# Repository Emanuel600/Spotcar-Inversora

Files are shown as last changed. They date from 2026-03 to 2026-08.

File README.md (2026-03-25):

# Spotcar Inversora
Projeto TCC, constituindo uma repuxadeira elétrica. Planilha de cálculo no arquivo Planilha_de_Cálculo.pynb; separado nas seguintes partes:
 - "Kicad - Projects" - placas que serão construídas, inclui versões alternativas que não serão utilizadas
 - "Spotcar Codebase" - código do microcontrolador escolhido

## Visão Geral
 - Visa principalmente reduzir volume, peso e custo do produto atualmente no mercado (50x40x40cm e 19,5 kg)
 - Deve ser capaz de realizar solda por resistência através da ponteira de solda (mínimo 10A, máximo ~200A)
 - Utilizada para desamassar peças metálicas de carros - não recomendada para lataria de alumínio

## Especificações Técnicas do Sistema
 - Tensão de entrada 220 V @ 60 Hz
 - Potência nominal de saída 2 kVA
 - Corrente máxima de saída 200 A
 - Frequência da corrente de saída 40 kHz
 - Tensão RMS de saída em vazio 10 V (onda quadrada)
 - Tecnologia inversora (Dada a potência, provável o uso de IGBTs)
 - Proteção de sobrecorrente, sobretemperatura e possívelmente subtensão na entrada

## Topologia
Devido à potência relativamente baixa e para reduzir a complexidade do comando - foi escolhida a topologia meia ponte.

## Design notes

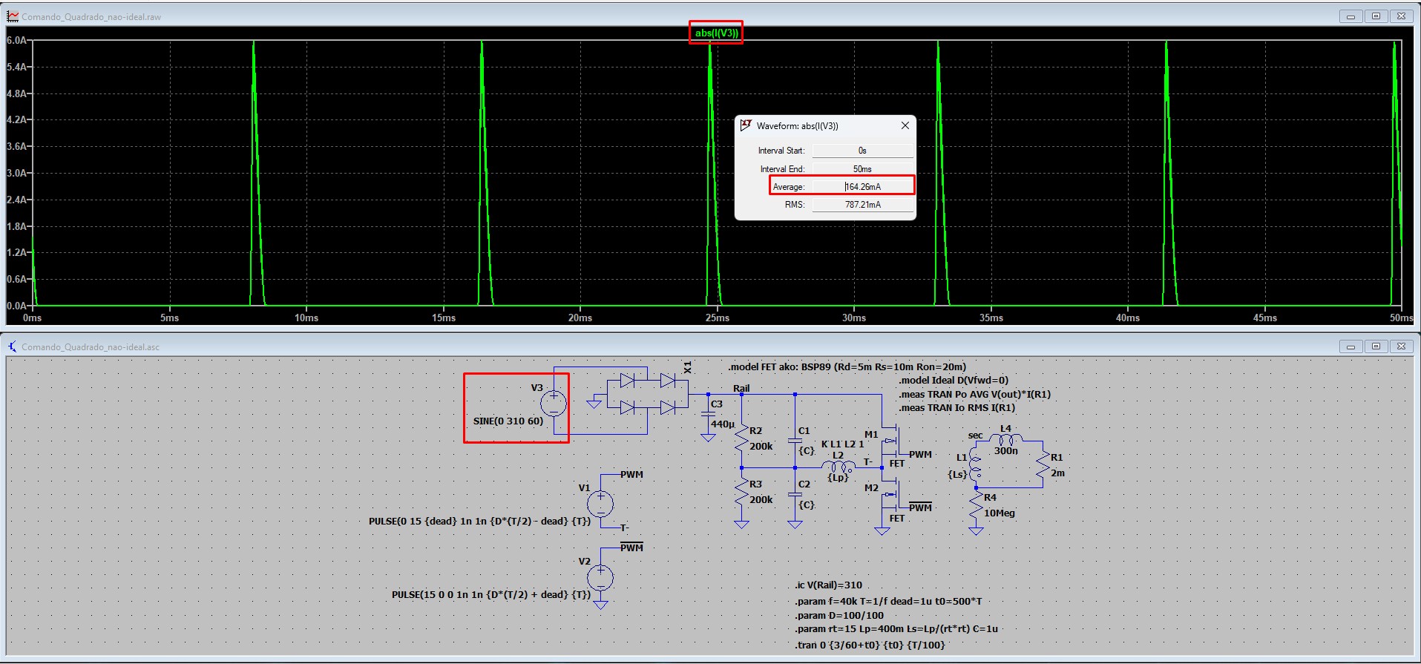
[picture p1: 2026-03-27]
screenshot.jpg

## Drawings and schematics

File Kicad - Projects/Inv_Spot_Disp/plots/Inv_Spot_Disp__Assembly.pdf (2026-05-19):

33u C1

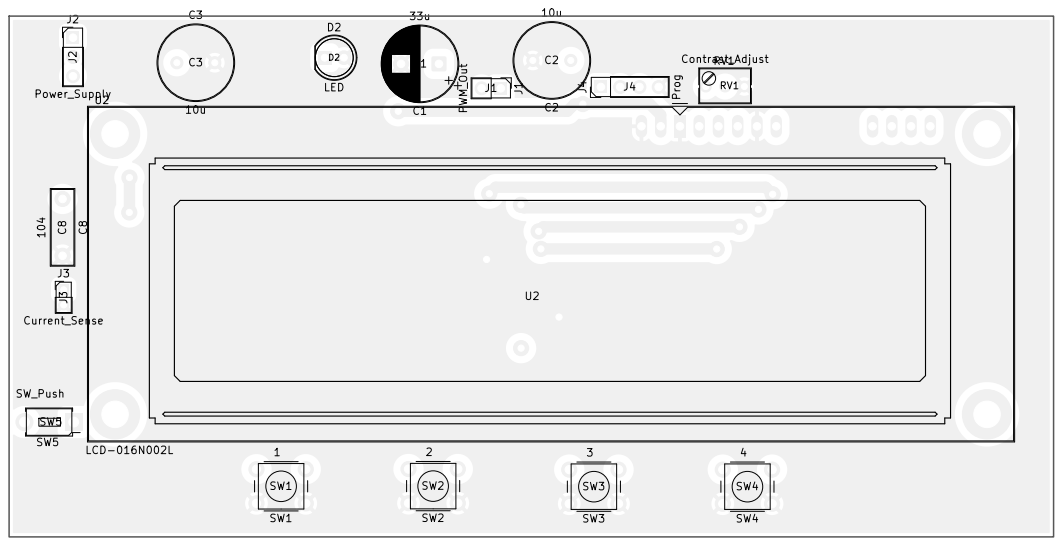
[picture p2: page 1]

Board2Pdf: Black And White TOP - Page 1/2

Sheet: Black And White TOP
File: Inv_Spot_Disp.kicad_pcb
Title:
KiCad E.D.A. 10.0.1

Board2Pdf: Black And White BOT - Page 2/2 ¹k5 | R14 4k | R4 | 104 C6 | 3k3

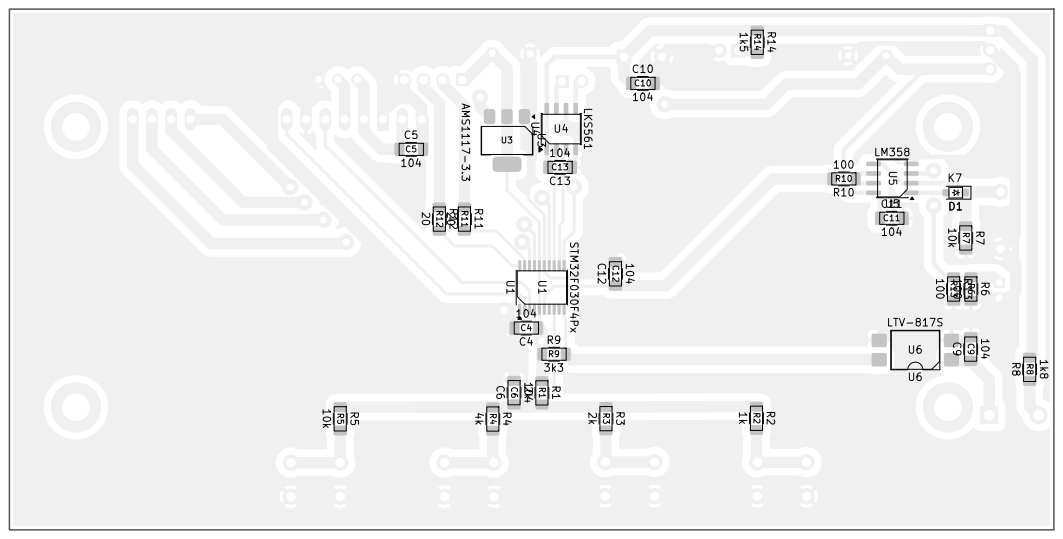
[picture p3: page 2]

Sheet: Black And White BOT
File: Inv_Spot_Disp.kicad_pcb
Title:
KiCad E.D.A. 10.0.1

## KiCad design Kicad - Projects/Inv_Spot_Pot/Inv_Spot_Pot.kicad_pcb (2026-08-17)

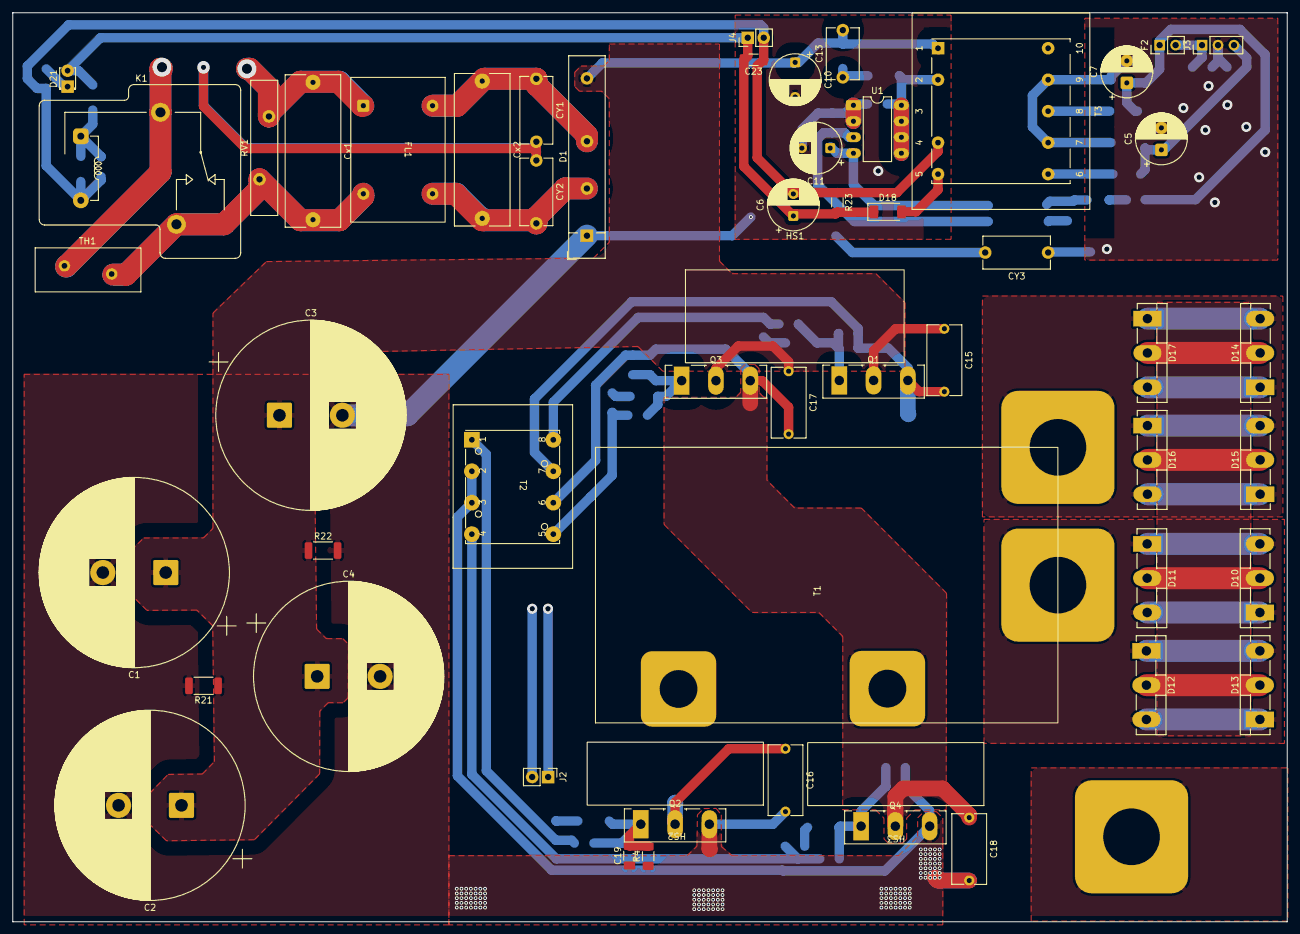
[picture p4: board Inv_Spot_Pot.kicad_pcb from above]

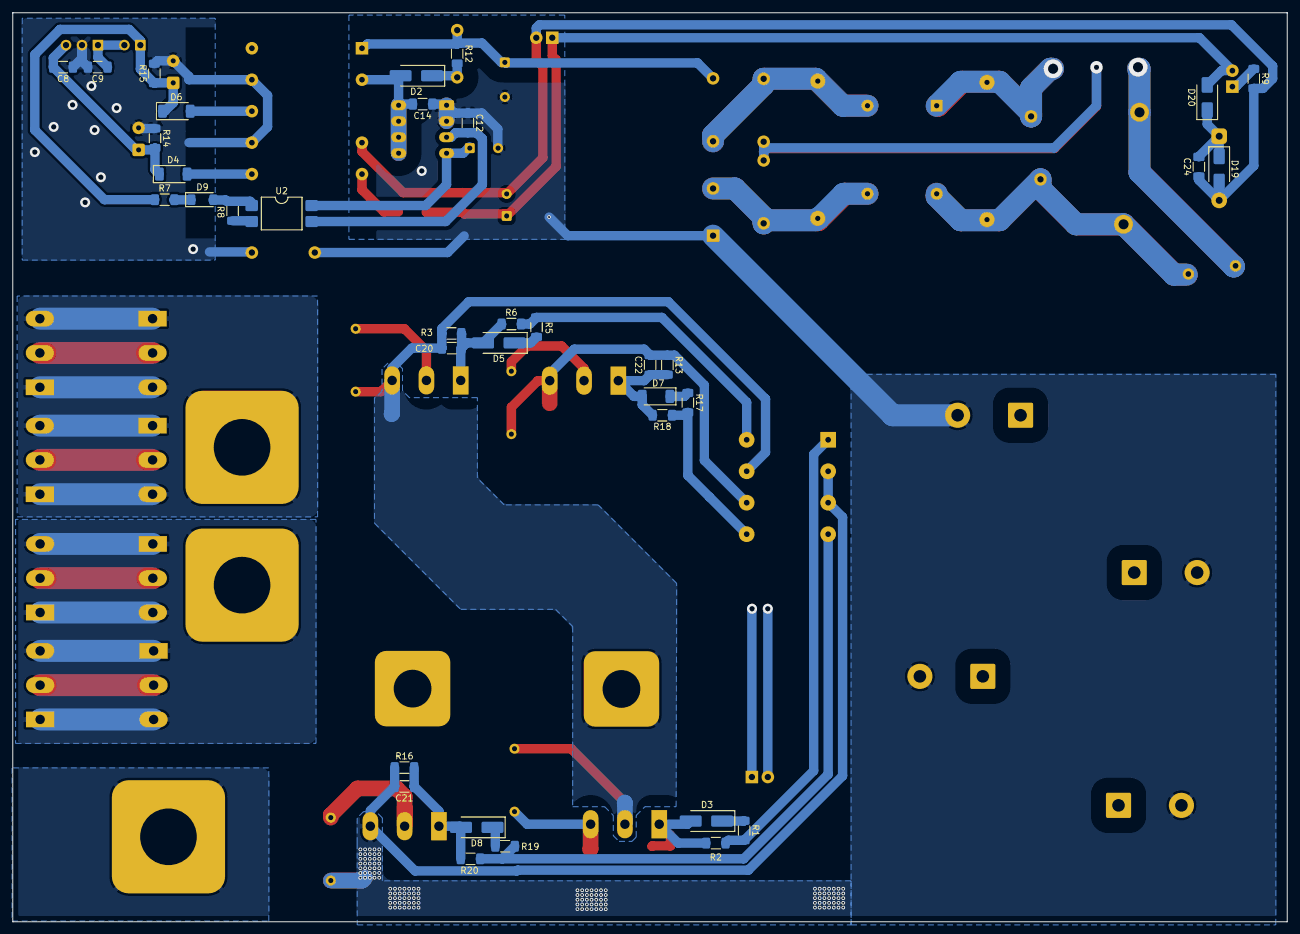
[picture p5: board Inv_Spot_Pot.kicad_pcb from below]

Board: 2 copper layers, 202.6 x 144.5 mm, 91 parts (36 on the bottom side), 42 nets.

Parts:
C1, C2, C3, C4: 220u; CP_Radial_D30.0mm_P10.00mm_SnapIn
C5, C6, C7: 220u; CP_Radial_D8.0mm_P3.50mm
C8, C9, C14, C19, C20, C21, C22, C23, C24: 100n; C_1206_3216Metric_Pad1.33x1.80mm_HandSolder
C10, C11: 47u; CP_Radial_D8.0mm_P3.50mm
C12: 1n; C_1206_3216Metric_Pad1.33x1.80mm_HandSolder
C13: 47p; C_Disc_D8.0mm_W5.0mm_P7.50mm
C15, C16, C17, C18: 100n; C_Rect_L11.0mm_W5.3mm_P10.00mm_MKT
CY1, CY2, CY3: C; C_Disc_D10.5mm_W5.0mm_P10.00mm
Cx1, Cx2: C; C_Rect_L24.0mm_W8.6mm_P22.50mm_MKT
D1: KBU4M; Diode_Bridge_32.0x5.6x17.0mm_P10.0mm_P7.5mm
D2: K7; D_SMA_Handsoldering
D3, D5, D8: SS16; D_SMA_Handsoldering
D4, D6, D7, D18: SS16; D_SOD-128
D9: BZV55B15; D_MiniMELF
D10, D11, D12, D13, D14, D15, D16, D17: MUR80G20; TO-3P-3_Vertical
D19, D20: 1N4007; D_SMA
D21: LED; LED_D1.8mm_W3.3mm_H2.4mm
F2: Polyfuse; PinHeader_1x02_P2.54mm_Vertical
FL1: EMI_Choke; Filtro_Choke
HS1: Heatsink; Heatsink_35x15mm
HS2, HS3: Heatsink; Floating_28x15x70mm
J2: PWM; PinHeader_1x02_P2.54mm_Vertical
J3: Display_Power; PinHeader_1x03_P2.54mm_Vertical
J4: 24V; PinHeader_1x02_P2.54mm_Vertical
K1: Y14x-1C-xxDS; Relay_SPDT_RAYEX-L90
Q1, Q2, Q3, Q4: 40T120; TO-247-3_Vertical
R1, R5, R17, R19: 2; R_1206_3216Metric_Pad1.30x1.75mm_HandSolder
R2, R6, R18, R20: 27; R_1206_3216Metric_Pad1.30x1.75mm_HandSolder
R3, R4, R13, R14, R15, R16, R23: 10k; R_1206_3216Metric_Pad1.30x1.75mm_HandSolder
R7: 510; R_1206_3216Metric_Pad1.30x1.75mm_HandSolder
R8, R12: 2k; R_1206_3216Metric_Pad1.30x1.75mm_HandSolder
R9: 2k2; R_1206_3216Metric_Pad1.30x1.75mm_HandSolder
R21, R22: 200k; R_2010_5025Metric
RV1: Varistor; RV_Disc_D21.5mm_W4.3mm_P10mm
T1: Transformer_1P_2S; Transformer_Toroid_THT_7032
T2: Pulse_Transformer-EEL-25_26x20-4_Windings
T3: Transformer_Breve_TEZ-28x33
TH1: Thermistor_PTC; RV_Disc_D16.5mm_W6.7mm_P7.5mm
U1: DIP-8_W7.62mm_LongPads
U2: LTV-817S; SMDIP-4_W9.53mm

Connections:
7V: C5.1, C8.2, D4.1 (K), J3.3, R14.2
15V: C9.1, F2.2, J3.1
24V: C6.1, C23.2, D18.1 (K), D20.2 (A), D21.2 (A), J4.1, R23.2
310V: C1.1, C2.1, C3.1, C4.1, C10.1, C13.2, C15.1, C17.1, D1.4 (+), Q1.2 (C), Q3.2 (C), R12.1, R21.1, R22.1, T3.1
/Soft_Start-24V/AC_{1}: K1.5, TH1.1
/Soft_Start-24V/AC_{2}: Cx1.1, FL1.1, RV1.1
/Soft_Start-24V/~AC{1}: Cx1.2, FL1.3, K1.1, RV1.2, TH1.2
Earth: C1.2, C2.2, C3.2, C4.2, C10.2, C11.2, C12.1, C14.1, C16.2, C18.2, C19.1, C21.2, CY3.2, D1.1 (-), Q2.3 (E), Q4.3 (E), R4.1, R16.1, R21.2, R22.2, T2.2, T2.3, U1.1 (GND), U1.2 (GND)
Earth_Protective: CY1.2, CY2.1
GND: C5.2, C7.2, C8.1, C9.2, CY3.1, J3.2, R8.2, R14.1, R15.2, T3.7, T3.9, U2.2
GND_{24}: C6.2, C23.1, C24.1, D19.2 (A), J4.2, K1.3, R9.2, R23.1, T3.4
Gate: C20.2, D5.2 (A), Q1.1 (G), R3.2, R6.1
Gate1: C22.1, D7.2 (A), Q3.1 (G), R13.2, R18.1
unnamed: CY1.1, Cx2.1, D1.3, FL1.2
unnamed: CY2.2, Cx2.2, D1.2, FL1.4
unnamed: C14.2, D2.2 (A), T3.2, U1.5 (drain), U1.6 (drain), U1.7 (drain), U1.8 (drain)
unnamed: C13.1, D2.1 (K), R12.2
unnamed: D3.1 (K), R1.1
unnamed: D4.2 (A), T3.6
unnamed: D5.1 (K), R5.1
unnamed: D6.2 (A), T3.8
unnamed: C7.1, D6.1 (K), F2.1, R7.1, R15.1
unnamed: D7.1 (K), R17.1
unnamed: D8.1 (K), R19.1
unnamed: D9.2 (A), R8.1, U2.1
unnamed: D9.1 (K), R7.2
unnamed: D18.2 (A), T3.5
unnamed: C24.2, D19.1 (K), D20.1 (K), K1.4
unnamed: D21.1 (K), R9.1
unnamed: C12.2, U1.3 (FB), U2.3
unnamed: C11.1, U1.4 (Vcc), U2.4
Out1: D10.1 (K), D10.3 (K), D11.1 (K), D11.3 (K), D12.1 (K), D12.3 (K), D13.1 (K), D13.3 (K), T1.3 (SA)
Out2: D14.1 (K), D14.3 (K), D15.1 (K), D15.3 (K), D16.1 (K), D16.3 (K), D17.1 (K), D17.3 (K), T1.6 (SD)
Out+: D10.2 (A), D11.2 (A), D12.2 (A), D13.2 (A), D14.2 (A), D15.2 (A), D16.2 (A), D17.2 (A)
PWM: R5.2, R6.2, T2.8
PWM1: R17.2, R18.2, T2.5
T+: C17.2, C18.1, C22.2, Q3.3 (E), Q4.2 (C), R13.1, T1.1 (AA), T2.6
T-: C15.2, C16.1, C20.1, Q1.3 (E), Q2.2 (C), R3.1, T1.2 (AB), T2.7
~Gate1: C21.1, D8.2 (A), Q4.1 (G), R16.2, R20.1
~Gate: C19.2, D3.2 (A), Q2.1 (G), R2.1, R4.2
~PWM1: R19.2, R20.2, T2.4
~PWM: R1.2, R2.2, T2.1

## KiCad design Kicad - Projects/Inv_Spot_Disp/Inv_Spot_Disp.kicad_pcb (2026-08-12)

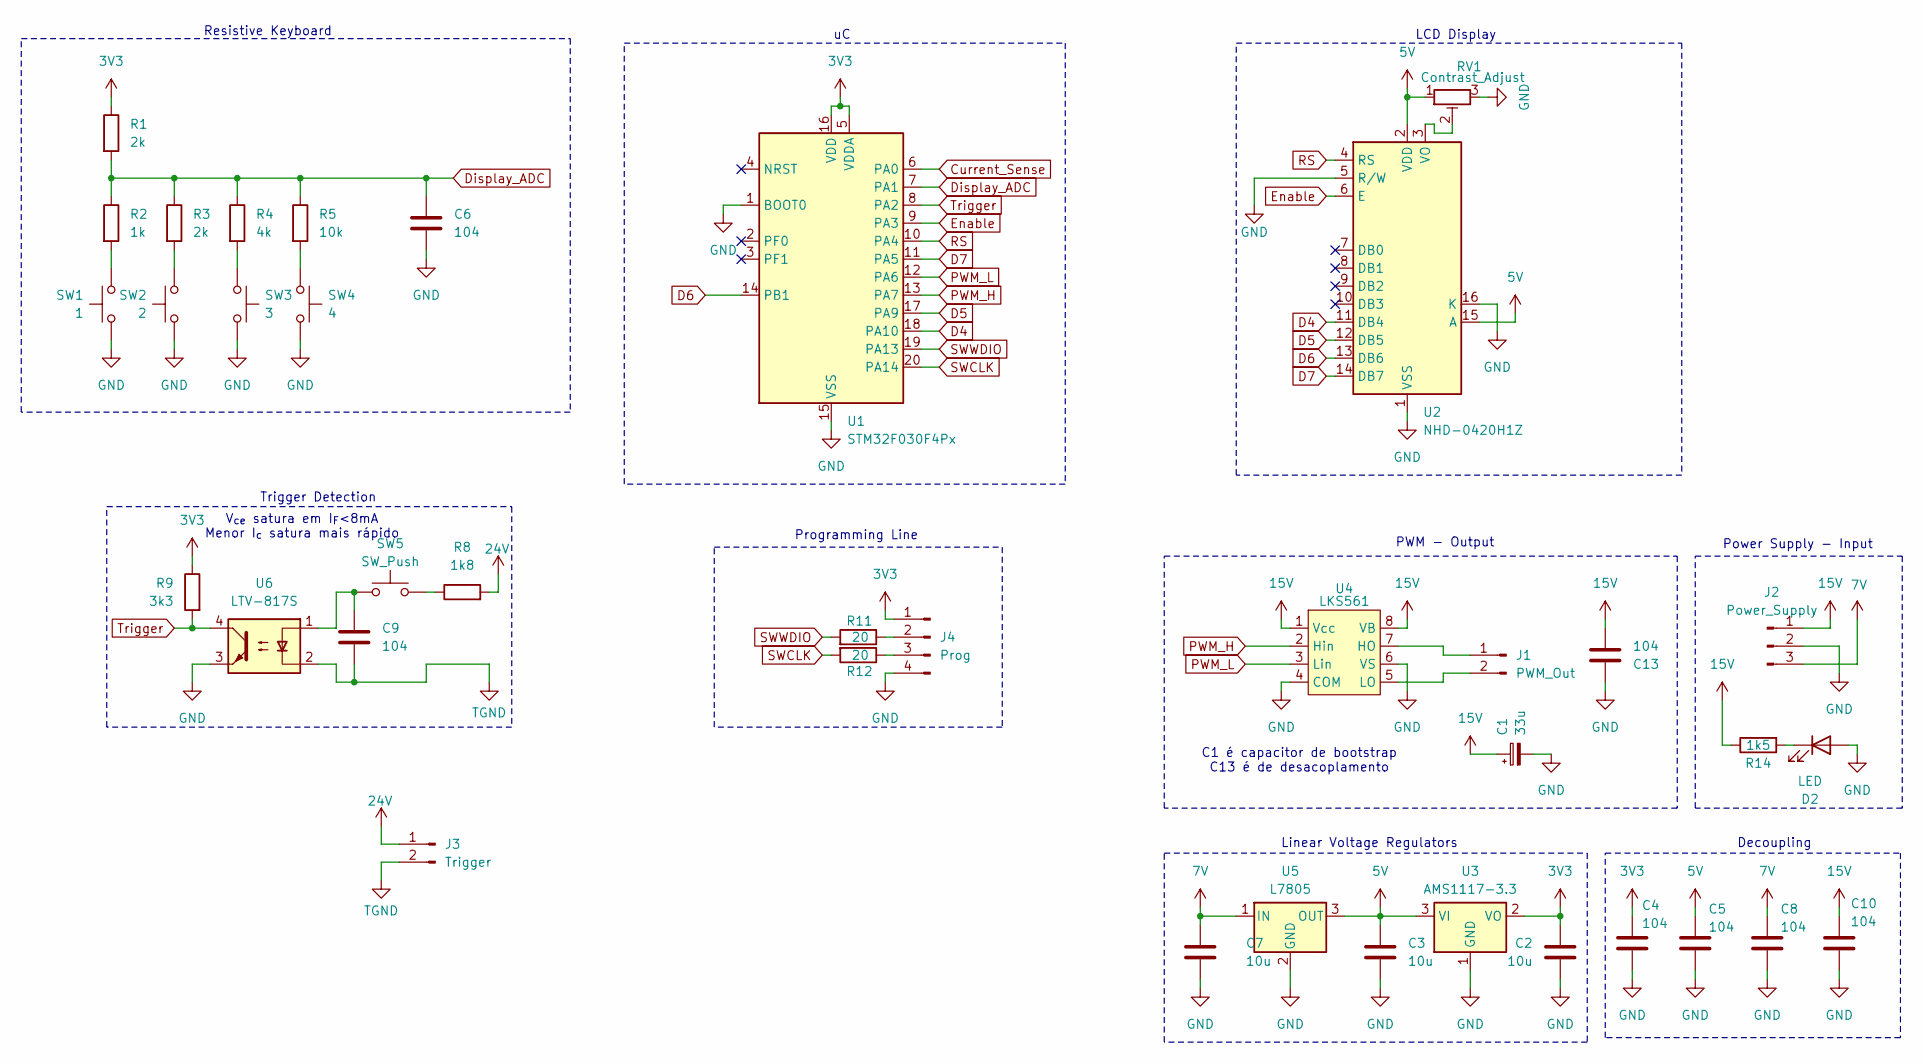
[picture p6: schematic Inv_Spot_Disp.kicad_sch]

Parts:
C1: 33u; CP_Radial_D10.0mm_P5.00mm
C2, C3, C7: 10u; C_Radial_D10.0mm_H12.5mm_P5.00mm
C4, C5, C6, C8, C9, C10, C13: 104; C_1206_3216Metric_Pad1.33x1.80mm_HandSolder
D2: LED; LED_D5.0mm
J1: PWM_Out; PinHeader_1x02_P2.54mm_Vertical
J2: Power_Supply; PinHeader_1x03_P2.54mm_Vertical
J3: Trigger; PinHeader_1x02_P2.54mm_Vertical
J4: Prog; PinHeader_1x04_P2.54mm_Vertical
R1, R3: 2k; R_1206_3216Metric_Pad1.30x1.75mm_HandSolder
R2: 1k; R_1206_3216Metric_Pad1.30x1.75mm_HandSolder
R4: 4k; R_1206_3216Metric_Pad1.30x1.75mm_HandSolder
R5: 10k; R_1206_3216Metric_Pad1.30x1.75mm_HandSolder
R8: 1k8; R_1206_3216Metric_Pad1.30x1.75mm_HandSolder
R9: 3k3; R_1206_3216Metric_Pad1.30x1.75mm_HandSolder
R11, R12: 20; R_1206_3216Metric_Pad1.30x1.75mm_HandSolder
R14: 1k5; R_1206_3216Metric_Pad1.30x1.75mm_HandSolder
RV1: Contrast_Adjust; Potentiometer_Bourns_3266Y_Vertical
SW1: 1; SW_PUSH_6mm_H13mm
SW2: 2; SW_PUSH_6mm_H13mm
SW3: 3; SW_PUSH_6mm_H13mm
SW4: 4; SW_PUSH_6mm_H13mm
SW5: SW_Push; SW_PUSH_1P1T_6x3.5mm_H4.3_APEM_MJTP1243
U1: STM32F030F4Px; TSSOP-20_4.4x6.5mm_P0.65mm
U2: NHD-0420H1Z; WC1602A
U3: AMS1117-3.3; SOT-223-3_TabPin2
U4: LKS561; SSOP-8_3.9x5.05mm_P1.27mm
U5: L7805; TO-252-2
U6: LTV-817S; SMDIP-4_W9.53mm

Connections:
3V3: C2.1, C4.1, J4.1, R1.1, R9.1, U1.5 (VDDA), U1.16 (VDD), U3.2 (VO)
5V: C3.1, C5.1, RV1.1, U2.2 (VDD), U2.15 (A), U3.3 (VI), U5.3 (OUT)
7V: C7.1, C8.1, J2.3, U5.1 (IN)
15V: C1.1, C10.1, C13.2, J2.1, R14.1, U4.1 (Vcc), U4.8 (VB)
24V: J3.1, R8.2
Current_Sense: U1.6 (PA0); also elsewhere on the board
D4: U1.18 (PA10), U2.11 (DB4)
D5: U1.17 (PA9), U2.12 (DB5)
D6: U1.14 (PB1), U2.13 (DB6)
D7: U1.11 (PA5), U2.14 (DB7)
Display_ADC: C6.1, R1.2, R2.1, R3.1, R4.1, R5.1, U1.7 (PA1)
Enable: U1.9 (PA3), U2.6 (E)
GND: C1.2, C2.2, C3.2, C4.2, C5.2, C6.2, C7.2, C8.2, C10.2, C13.1, D2.2 (A), J2.2, J4.4, RV1.3, SW1.1, SW2.1, SW3.1, SW4.1, U1.1 (BOOT0), U1.15 (VSS), U2.1 (VSS), U2.5 (R/W), U2.16 (K), U3.1 (GND), U4.4 (COM), U4.6 (VS), U5.2 (GND), U6.3; also elsewhere on the board
unnamed: C9.1, SW5.1, U6.1
unnamed: D2.1 (K), R14.2
unnamed: J1.1, U4.7 (HO)
unnamed: J1.2, U4.5 (LO)
unnamed: J4.2, R11.1
unnamed: J4.3, R12.1
unnamed: R2.2, SW1.2
unnamed: R3.2, SW2.2
unnamed: R4.2, SW3.2
unnamed: R5.2, SW4.2
unnamed: R8.1, SW5.2
unnamed: RV1.2, U2.3 (VO)
PWM_H: U1.13 (PA7), U4.2 (Hin)
PWM_L: U1.12 (PA6), U4.3 (Lin)
RS: U1.10 (PA4), U2.4 (RS)
SWCLK: R12.2, U1.20 (PA14)
SWWDIO: R11.2, U1.19 (PA13)
TGND: C9.2, J3.2, U6.2
Trigger: R9.2, U1.8 (PA2), U6.4

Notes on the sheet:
Programming Line
PWM - Output
Linear Voltage Regulators
C1 é capacitor de bootstrap C13 é de desacoplamento
V_{ce} satura em I_{F}<8mA Menor I_{c} satura mais rápido
Decoupling
Power Supply - Input
Trigger Detection
LCD Display
Resistive Keyboard

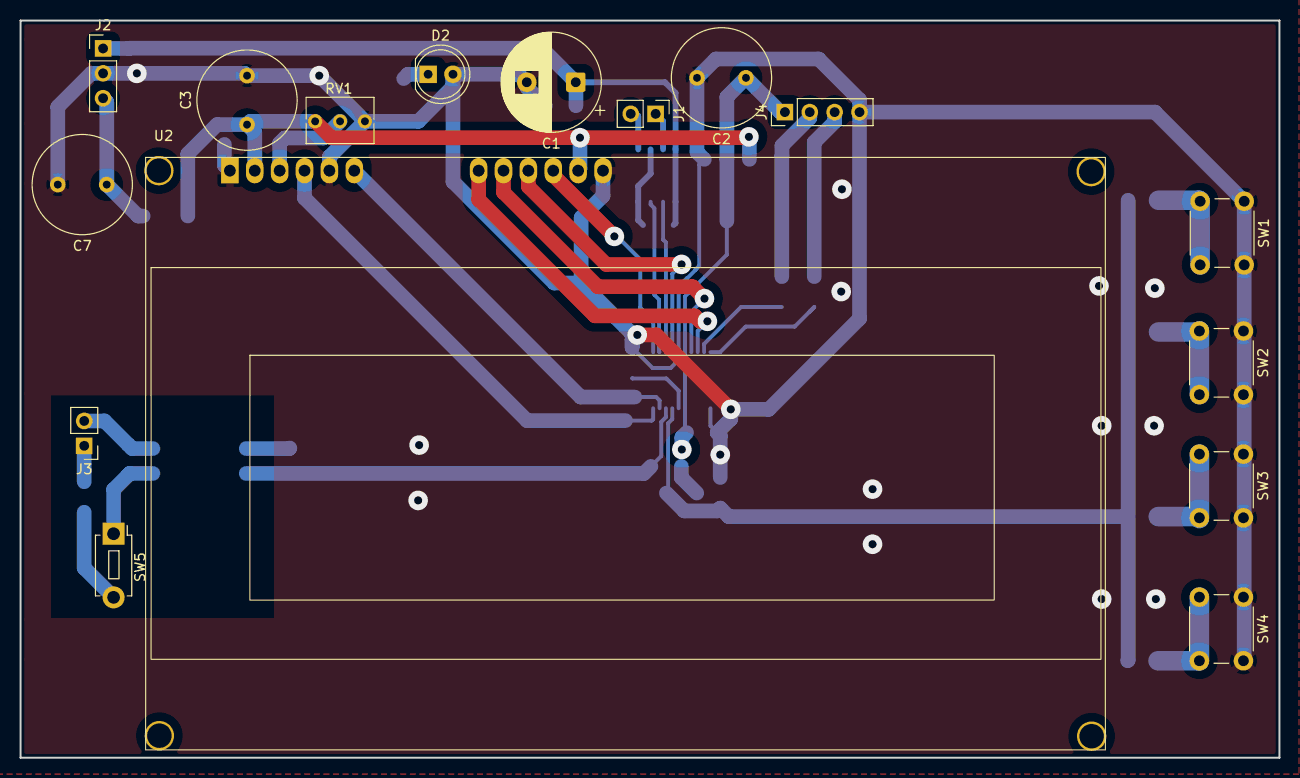
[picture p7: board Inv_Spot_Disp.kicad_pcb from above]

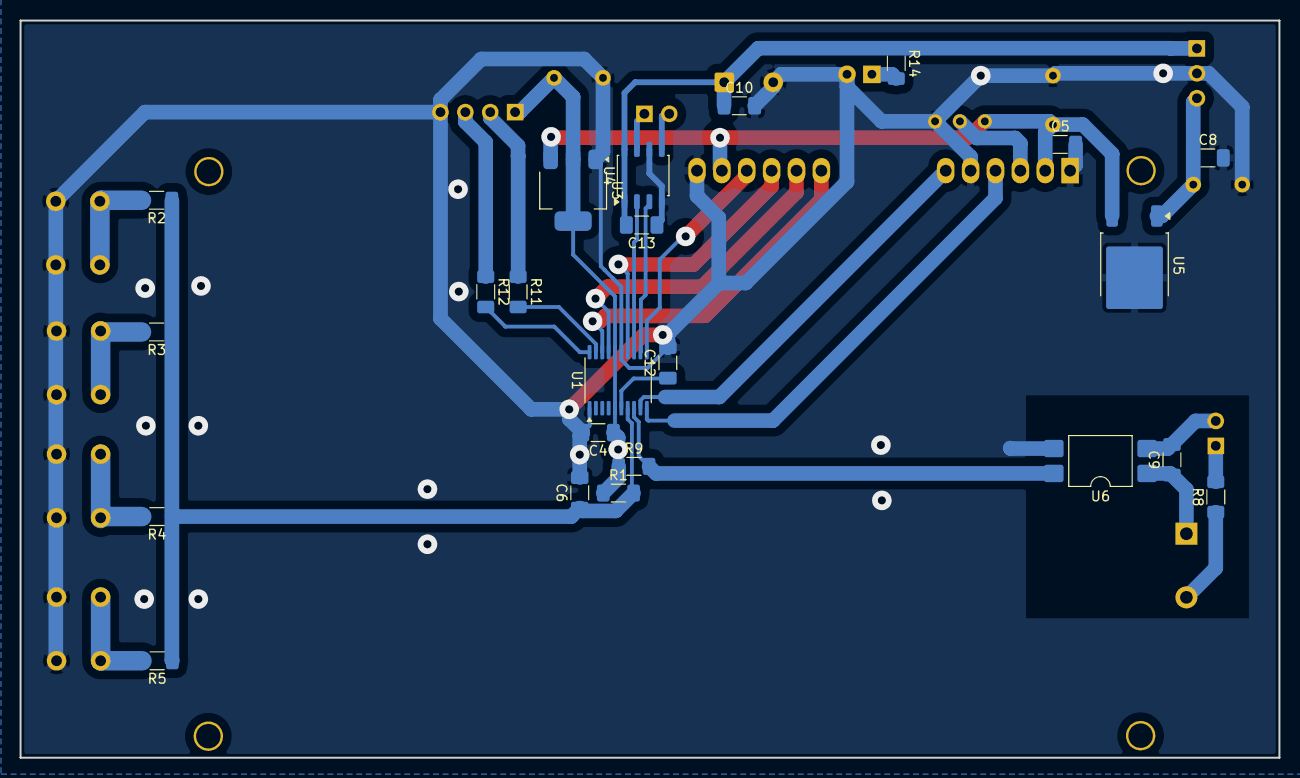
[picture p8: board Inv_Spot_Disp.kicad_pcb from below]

Board: 2 copper layers, 128.6 x 75.3 mm, 39 parts (23 on the bottom side), 32 nets.

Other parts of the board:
C12: 104; C_1206_3216Metric_Pad1.33x1.80mm_HandSolder

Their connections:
Current_Sense: C12.1; also elsewhere on the board
GND: C12.2; also elsewhere on the board

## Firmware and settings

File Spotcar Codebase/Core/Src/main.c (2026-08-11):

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
/* Includes ------------------------------------------------------------------*/
#include "main.h"
#include "adc.h"
#include "dma.h"
#include "tim.h"
#include "gpio.h"

/* USER CODE BEGIN Includes */
#include "HD44780.h"
#include "menu.h"
/* USER CODE END Includes */


/* USER CODE BEGIN PV */
uint16_t ADC_Readouts[2];
pin_s data_pins[] = {{D4_Pin, D4_GPIO_Port}, {D5_Pin, D5_GPIO_Port}, {D6_Pin, D6_GPIO_Port}, {D7_Pin, D7_GPIO_Port}};
pin_s e_rs_pins[] = {{Enable_Pin, Enable_GPIO_Port}, {RS_Pin, RS_GPIO_Port}};

uint32_t triggered = 0;
static uint32_t s_current = 0;
/* USER CODE END PV */

void SystemClock_Config(void);
/**
  * @brief  The application entry point.
  * @retval int
  */
int main(void)
{

  /* MCU Configuration--------------------------------------------------------*/

  /* Reset of all peripherals, Initializes the Flash interface and the Systick. */
  HAL_Init();

  /* Configure the system clock */
  SystemClock_Config();

  /* Initialize all configured peripherals */
  MX_GPIO_Init();
  MX_DMA_Init();
  MX_ADC_Init();
  MX_TIM1_Init();
  MX_TIM3_Init();
  /* USER CODE BEGIN 2 */
  //ADC_Calibrate(&hadc);
  HAL_ADC_Start_DMA(&hadc, (uint32_t*)ADC_Readouts, 2);
  HD_Init(data_pins, e_rs_pins);
  Set_Trigger_Pin(Trigger_Pin, Trigger_GPIO_Port);
  /* USER CODE END 2 */

  /* Infinite loop */
  /* USER CODE BEGIN WHILE */

  HD_Write_4_Lines(\
		  " Spotcar Inversora ", \
		  "     V8 Brasil     ", \
		  "  @V8BrasilOficial  ", \
		  "   (48) 3341-8600   ");
  HAL_Delay(2000);

  Create_Custom_Chars();

  uint32_t last_updated = HAL_GetTick();
  uint32_t last_trigger_check = HAL_GetTick();
  uint32_t Pulse = 0;

  volatile uint32_t trigger_time = 100;

  Set_Trigger_Time(&trigger_time);

  SET_DUTY_CYCLE(0);

  HAL_TIMEx_PWMN_Start(&htim1, TIM_CHANNEL_1);
  HAL_TIM_PWM_Start(&htim3, TIM_CHANNEL_1);

  while (1)
  {
	  if ((HAL_GetTick() - last_updated) > 200){
		  Read_Button_State(ADC_Readouts[1]);
		  Menu_Logic_Handler();

		  last_updated = HAL_GetTick();
	  }

	  // Checks if it needs to update at the start of the function
	  Menu_Update_Display();
	  // Trigger
	  if(((HAL_GetTick() - last_trigger_check) > 150) & Is_Trigger_Ready()){
	  		//ADC_Calibrate(&hadc);

		  // Preaquecer a peça

		  Operation_Mode op_mode = Get_Op_Mode();

		  switch (op_mode){
		  case OP_ESTRELA:
			  SET_DUTY_CYCLE(225);

			  HAL_Delay(10);
			  break;
		  case OP_ARRUELA:
			  break;
			  SET_DUTY_CYCLE(100);

			  HAL_Delay(10);
			  break;
		  default:
			  break;
		  }

		  SET_DUTY_CYCLE(0);

		  HAL_Delay(2);

		  last_trigger_check = HAL_GetTick();
		  Pulse = Current_Get_Compare();

		  SET_DUTY_CYCLE(Pulse);

		  if((op_mode == OP_COBRE) | (op_mode == OP_CARVAO) | (op_mode == OP_PARAFIX)){
			  Hold_Until_Trigger_Release();
		  } else{
			  HAL_Delay(trigger_time);
		  }

		  SET_DUTY_CYCLE(0);

		  if((op_mode == OP_ESTRELA) | (op_mode == OP_ARRUELA)){
			  Hold_Until_Trigger_Release();
		  }
	  }
	  // Stops trigger if gone over time

	  // Adjusts PWM for more or less current
	  /*
	   if(((HAL_GetTick() - trigger_start) > 2) & (triggered==1)){
		   // Adjusts Current Proportionally to Current Error
		   int32_t adjustment = 0;
		   // Safeguard to only activate when output current > 1A
		   if (s_current > 1000){
		   	   adjustment = 3*((int32_t)Get_Target_Current() - (int32_t)s_current)>>12;
		   }
		  Pulse += adjustment;
		  // Clamp pulse width
		  if (Pulse > 300){
			  Pulse = 300;
		  } else if (Pulse < 9){
			  Pulse = 9;
		  }
		  __HAL_TIM_SET_COMPARE(&htim1, TIM_CHANNEL_1, Pulse);
  		  __HAL_TIM_SET_COMPARE(&htim3, TIM_CHANNEL_1, Pulse);
	   }*/
    /* USER CODE END WHILE */

    /* USER CODE BEGIN 3 */
  }


  /* USER CODE END 3 */
}

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
/* USER CODE BEGIN 4 */
void HAL_ADC_ConvCpltCallback(ADC_HandleTypeDef* hadc){
	 s_current = (ADC_Readouts[0]*3300*124)>>12;
}
/*
void HAL_TIM_OC_DelayElapsedCallback(TIM_HandleTypeDef *htim)
{
    if (htim->Instance == TIM14 && htim->Channel == HAL_TIM_ACTIVE_CHANNEL_1)
    {
        // The hardware has already automatically stopped counting.
        // Clean up the software driver flag so it's clean for the next run:
        HAL_TIM_OC_Stop_IT(htim, TIM_CHANNEL_1);

        // Halt PWM generation from tim1 and tim3
        HAL_TIM_PWM_Stop(&htim3, TIM_CHANNEL_1);
        HAL_TIMEx_PWMN_Stop(&htim1, TIM_CHANNEL_1);
        triggered = 0;
    }
}
*/
/* USER CODE END 4 */
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


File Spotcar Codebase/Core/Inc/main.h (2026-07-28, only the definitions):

#define Enable_Pin GPIO_PIN_0
#define Enable_GPIO_Port GPIOF
#define RS_Pin GPIO_PIN_1
#define RS_GPIO_Port GPIOF
#define Current_Sense_Pin GPIO_PIN_0
#define Current_Sense_GPIO_Port GPIOA
#define Display_ADC_Pin GPIO_PIN_2
#define Display_ADC_GPIO_Port GPIOA
#define Trigger_Pin GPIO_PIN_4
#define Trigger_GPIO_Port GPIOA
#define D4_Pin GPIO_PIN_5
#define D4_GPIO_Port GPIOA
#define D5_Pin GPIO_PIN_1
#define D5_GPIO_Port GPIOB
#define D6_Pin GPIO_PIN_9
#define D6_GPIO_Port GPIOA
#define D7_Pin GPIO_PIN_10
#define D7_GPIO_Port GPIOA

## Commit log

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2026-03-23 Kicad files
    Should've been included in last commit but got hidden by a discarded git repo
    [Driver.kicad_sch, Inv_Spot_Disp.kicad_pcb, Inv_Spot_Disp.kicad_sch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]
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2026-03-31 Updated PCB
    Fixed some footprints, increased insulation and improved board segmentation - segmentation still needs some work
    [Driver.kicad_sch, Inv_Spot_Pot.kicad_pcb, Inv_Spot_Pot.kicad_sch]
2026-04-10 Final revision for board with driver IC
    Última revisão da placa com driver IR2110 - para melhor flexibilidade e aproveitamento de espaço da placa, foi decidido explorar o projeto com um transformador de gate drive EE-25
    Poderia ser utilizado um transformador EE-19 e poupar espaço, mas por disponibilidade imediata foi utilizado o EEL-25
    [Inv_Spot_Pot.kicad_pcb, Inv_Spot_Pot.kicad_sch]
2026-04-10 Half bridge prototype
    IR2110 completamente substituído por transformador de gate, falta corrigir footprint do transformador de saída e fazer placa alternativa de ponte completa
    [Inv_Spot_Pot.kicad_pcb, Inv_Spot_Pot.kicad_sch]
2026-04-13 Resistor CE
    Adicionado resistor coletor-emissor na placa, corrigido erro na direção do diodo do circuito de drive dos IGBTs
    Melhora nos planos de referência - Alguns pontos ainda apresentam caminho de retorno longos, mas talvez isso possa ser corrigido na própria placa
    [Inv_Spot_Pot.kicad_pcb, Inv_Spot_Pot.kicad_sch]
2026-04-14 Melhora de Isolamento
    Removido parte do plano preenchido no circuito de gate drive da chave superior para manter distância do isolamento elétrico
    [Inv_Spot_Pot.kicad_pcb]
2026-04-15 General Polishing
    Removidos furos dos dissipadores que não serão utilizados, aberto espaço previsto para relé e circuito de tensão auxiliar
    Falta ainda corrigir o footprint do transformador (bobinar) e a placa base de display que será utilizada
    [Inv_Spot_Pot.kicad_pcb, Inv_Spot_Pot.kicad_sch]
2026-04-20 Adicionando Fonte Auxiliar
    Fonte auxiliar com topologia flyback dimencionada, falta criar o footprint do transformador, abrir o espaço na placa e finalizar o roteamento dos componentes
    [Inv_Spot_Disp.kicad_pcb, Inv_Spot_Disp.kicad_sch, Inv_Spot_Pot.kicad_pcb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]
2026-04-21 Adicionado Flyback (WIP)
    Adicionado circuito auxiliar flyback - footprint ocupa bastante espaço e aumenta significativamente a altura da placa.
    Revendo layout para tentar melhorar o particionamento da placa
    [Inv_Spot_Pot.kicad_pcb, Inv_Spot_Pot.kicad_sch]
2026-04-22 Ajuste da Auxiliar
    Fonte auxiliar ajustada, ainda não satisfeito com o resultado
    [Inv_Spot_Pot.kicad_pcb]
2026-04-22 Primeira Versão - Ponte Completa
    Desnho inicial da placa de ponte completa
    Contém principalmente o seccionamento da placa, sem conexões próprias ainda
    [Inv_Spot_Pot.kicad_pcb, Inv_Spot_Pot.kicad_sch]
2026-04-27 Ajustes Preliminares
    Ajustes preliminares feitos na placa para modificá-la à um circuito ponte completa
    À fazer:
    - trocar posição dos IGBTs high e low-side
    - Trocar entrada do sensor de corrente para T+ (trocar posição no transformador também)
    - Adicionar filtros básicos (será unicializada a placa de display primeiro devido ao teste de carga)
    [Inv_Spot_Pot.kicad_pcb, Inv_Spot_Pot.kicad_sch]
2026-04-28 Melhoras na Ponte Completa
    Placa de ponte completa quase feita, falta rotear os PWMs e adicionar o cabo que leva T- ao transformador
    Removido arquivo .history devido a incomodar na hora de uppar os arquivos
    [Inv_Spot_Pot.kicad_pcb, Inv_Spot_Pot.kicad_sch]
2026-04-28 Ajustes Gerais
    Ajustando footprints e esquemáticos, falta ajuste final no esquemático e footprint do transformador de drive
    [Inv_Spot_Pot.kicad_pcb, Inv_Spot_Pot.kicad_sch]
2026-04-29 Ajustes Semi-Finais
    Adicionados circuitos de gate e capacitores de polipropileno, falta apenas o footprint final do transformador e os capacitores de segurança em Y na fonte auxiliar e saída da linha AC
    [Inv_Spot_Pot.kicad_pcb, Inv_Spot_Pot.kicad_sch]
2026-04-29 Final - Placa Ponte Completa
    Ajustadas todas as rotas da placa de potência por ponte completa, falta apenas adicionar test-points
    [Inv_Spot_Pot.kicad_pcb, Inv_Spot_Pot.kicad_sch]
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2026-04-29 Adicionados Testpoints
    Adicionados testpoints:
    - Gate de cada IGBT (+ emissor)
    - Tensão do barramento
    - Barramento da fonte auxiliar
    Trocado footprint do sensor de corrente para pinheader
    [Inv_Spot_Pot.kicad_pcb, Inv_Spot_Pot.kicad_sch]
2026-04-30 Finalizada Placa de Potência
    Capacitor de desacoplamento de 15V da fonte auxiliar movido para estar mais próximo da saída
    Footprint do transformador corrigida
    PWM da camada de cima afastado do dissipador de Q2
    Maior afastamento entre planos GND/Earth e trilhas na fonte auxiliar
    Modificado símbolo do transformador de saída no esquemático para melhor refletir a saída
    [Inv_Spot_Pot.kicad_pcb, Inv_Spot_Pot.kicad_sch]
2026-04-30 Ajustes de Esquemático - Display
    Ajustes no esquemático da placa de display:
    - Removido trigger do teclado resistivo
    - Melhora do circuito de detecção de corrente
    - Simplificação do circuito de drive - falta adicionar filtro RC antes da saída
    - Implementar Opto para leitura digital do gatilho de disparo
    - Trocar footprints para Pin Header/SMD
    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
    [Inv_Spot_Disp.kicad_sch]
2026-05-04 Ajustes de Esquemático - Display
    Feito:
    - Ajustes genéricos para melhor legibilidade
    - Implementado Opto para leitura do gatilho (com pull-up no lado do uC)
    - Trocados footprints das conexões para pinheader
    - Ajuste na trilha T- do IGBT superior
    - Trocar todos os resistores por SMD
    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
    [Inv_Spot_Disp.kicad_sch, Inv_Spot_Pot.kicad_pcb]
2026-05-04 Ajustado Pinout - uC
    - Adicionado capacitor de bootstrap no driver
    - Ajustado pinout do uC, código gerador de PWM teve que ser alterado para manter ação de gate simétrica
    - Enrolado secundário do transformador
    - Discutido com Anderson sobre esquemáticos e layouts
    - Rotear PCB
    - Corrigir footprints do teclado resistivo
    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
    [Inv_Spot_Disp.kicad_sch]
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2026-05-04 Geração de Código
    Gerado o código para a nova geração de PWM
    Adicionados elementos na PCB
    Footprints corrigidos
    [Inv_Spot_Disp.kicad_pcb, Inv_Spot_Disp.kicad_sch]
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2026-05-05 Primeiro Layout - Display
    Feito o layout preliminar da placa de display, conferir com o Anderson
    Corrigido problema com o layout do transformador (erro no símbolo utilizado levou a inversão dos IGBTs superiores)
    [Inv_Spot_Disp.kicad_pcb, Inv_Spot_Disp.kicad_sch, Inv_Spot_Pot.kicad_pcb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]
2026-05-07 Ajustes Finais
    Ajustes em larguras de trilha da camada top
    Ajuste do footprint dos capacitores de polipropileno dos IGBTs
    Ajuste dos planos de referência
    [Driver.kicad_sch, Inv_Spot_Disp.kicad_pcb, Inv_Spot_Pot-free.kicad_pcb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]
2026-05-07 Ponto de Teste Restaurado
    Alteração prévia acidentalmente removeu ponto de teste no gate (Q1), adicionado novamente
    [Inv_Spot_Pot.kicad_pcb]
2026-05-08 Ajustes de Footprint
    Ajustadas footprints para valores disponíveis
    Falta:
    - Adicionar GND e 5V nos pinos de programação do display
    - Adicionar resistor de 5V para Temp_Sense, possibilitando leitura de temperatura
    [Inv_Spot_Pot.kicad_pcb, Inv_Spot_Pot.kicad_sch]
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2026-05-15 Correção - Timers e Estimativa
    Corrigido o código que inicia a geração do PWM e que estima a corrente
    Ajustado para que o ciclo de trabalho esteja limitado à 50% no máximo e utilizando os timers corretos para geração de PWM
    [main.c, menu.c]
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2026-05-22 Corrigido Cálculo Grosso da Corrente
    Cálculo da corrente retornava valores errados, corrigido
    [menu.c]
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2026-05-26 Consertados Labels dos Pinos
    Label dos pinos do display agora refletem os que serão usados do módulo
    Também corrigida lógica de mascara utilizada na função de comando
    [HD44780.c, Spotcar Codebase.ioc, main.c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]
2026-05-27 Adicionada Tela Inicial
    Adicionada tela inicial com informações de contato e telefone
    Corrigida lógica de controle do display
    Corrigido cálculo da corrente pelo ADC
    [Inv_Spot_Disp.kicad_pcb, Inv_Spot_Pot-Panel.kicad_pcb, Inv_Spot_Pot.kicad_pcb]
2026-05-29 Ajustes de Documentação
    Ajustada documentação do módulo LCD e corrigido erro de máscara na função HD_Set_Cursor
    Ajustada também posição de capacitor de desacoplamento do sinal do sensor da corrente para ser mais próximo do ADC.
    [Inv_Spot_Disp.kicad_pcb]
2026-06-09 Corrigido Footprint do Display
    Corrigido problema com o footprint do display
    Melhora o caminho de retorna das trilhas de programação
    Aumento na quantidade de vias para reduzir impedância do plano terra
    [Inv_Spot_Disp.kicad_pcb, Inv_Spot_Disp.kicad_sch, Inv_Spot_Pot-Panel.kicad_pcb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]
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2026-06-12 Big Fixes
    Running out of time
    [HD44780.c, Spotcar Codebase.ioc, main.c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]
2026-06-16 Fixed Trigger Detection
    Trigger detection was not using the right pins
    [Spotcar Codebase.ioc, main.c, menu.c]
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2026-07-27 Ajuste - Geração de PWM
    Ajuste na geração de PWM e adição de temporização ajustável para a máquina.
    Redução de glitch no início e fim do trem de pulsos gerados, removendo glitch de assimetria de ~50us para apenas um meio ciclo mais fino (~20u).
    Adicionadas opções de temporização e ciclos de pré-aquecimento únicos para cada modo de operação.
    Exploração da PCB para planejar alterações.
    [Inv_Spot_Pot.kicad_pcb]
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2026-08-07 Semi-final Touches
    Menu now uses power instead of current
    Removed pulsed timing from "CARVAO" and "ARRUELA" operation modes
    Added parafix mode
    Fixed schematic for output transformer
    Added rectification on the output
    Trying different power trace geometry in antecipation of voltage spikes
    [Inv_Spot_Disp.kicad_pcb, Inv_Spot_Disp.kicad_sch, Inv_Spot_Pot.kicad_pcb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]
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2026-08-17 Cleaning Up
    Cleaning up silkscreen collisions and no longer needed dimensions on the PCB viewer
    [Inv_Spot_Pot.kicad_pcb, Inv_Spot_Pot.kicad_sch]
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2026-10-23 Alteração Menu
    Correção de bugs de display no menu de corrente
    Última versão da placa de potência com footprint do transformador de protótipo
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

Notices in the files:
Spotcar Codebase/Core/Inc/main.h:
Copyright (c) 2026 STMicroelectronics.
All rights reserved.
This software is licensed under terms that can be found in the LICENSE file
